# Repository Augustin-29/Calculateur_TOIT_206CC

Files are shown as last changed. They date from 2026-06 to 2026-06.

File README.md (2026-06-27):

# Calculateur TOIT 206CC (Version 1)

Ce projet open-source consiste en la rétro-ingénierie et la conception d'un calculateur de remplacement sur mesure pour la gestion du toit escamotable d'une Peugeot 206 CC. La V1 s'appuie sur une architecture matérielle moderne et un système d'exploitation temps réel pour piloter de manière fiable et sécurisée le cycle d'ouverture/fermeture du toit.

---

## 🛠️ Architecture du Projet

Le dépôt regroupe l'ensemble du projet dans une structure centralisée :
*   **`CAO/`** : Conception matérielle complète sous KiCad (Schématiques, empreintes spécifiques, modélisations 3D et fichiers de fabrication Gerber).
*   **`CODE_CT_V1/`** : Logiciel embarqué développé en C/C++ avec une structure de build basée sur CMake.

---

## 💾 Spécifications Techniques (Hardware)

Le module remplace l'électronique d'origine en modernisant la chaîne de traitement et de commande.

*   **Microcontrôleur principal** : STM32F103 (Cortex-M3), choisi pour sa gestion des périphériques et ses timers avancés nécessaires à l'acquisition des capteurs de position.
*   **Interface Véhicule & Diagnostic** : Support de la ligne K (K-line) pour la communication de diagnostic et l'analyse de protocole.
*   **Connectique d'Origine** : Intégration sur le PCB d'une empreinte sur mesure pour le connecteur jaune 26 broches spécifique au faisceau habitacle de la 206 CC.
*   **Routage & Puissance** : 
    *   Routage optimisé des pistes de puissance pour la gestion des courants des moteurs de pompe hydraulique et des actionneurs.
    *   Protection renforcée de l'étage d'alimentation face aux contraintes du réseau électrique automobile (transitoires, variations de tension).
    *   Isolation et conditionnement des signaux des micro-contacts (capteurs de fin de course des éléments du toit et du coffre).

---

## 💻 Logiciel Embarqué (Firmware)

Le code est architecturé pour garantir le déterminisme et la sécurité lors des mouvements mécaniques du toit.

*   **Système d'Exploitation** : Intégration de **FreeRTOS** pour orchestrer les tâches concurrentes (gestion de la machine d'état du toit, scrutation des capteurs, communications).
*   **Gestion de la Sécurité** : Tâches prioritaires surveillant en temps réel l'état des capteurs pour interrompre immédiatement le cycle en cas d'anomalie ou d'obstacle.
*   **Environnement de Développement** : Configuration complète sous **CMake**, facilitant la cross-compilation avec la chaîne d'outils `gcc-arm-none-eabi`.

---

## 📂 Contenu du dossier CAO

Le dossier de conception électronique inclut :
*   Le schéma structurel (`.kicad_sch`) et le routage du PCB (`.kicad_pcb`).
*   Les fichiers de fabrication indispensables (Générés dans `CAO/gerber/` : couches de cuivre, masques de soudure, sérigraphies et fichiers de perçage `.drl`).
*   Les modèles 3D des composants spécifiques (relais automobiles, connecteur jaune 26P, etc.) utilisés pour valider l'intégration mécanique de la carte dans son boîtier.

---

## 🚀 À venir (Roadmap V2)

*   Validation de la machine d'état sur banc de test et intégration véhicule.
*

---
*Projet développé par Augustin — 2026.*

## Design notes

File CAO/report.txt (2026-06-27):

Info: Traitement du symbole "C1:Capacitor_SMD:CP_Elec_8x10.5".
Info: Traitement du symbole "R12:Resistor_SMD:R_0805_2012Metric_Pad1.20x1.40mm_HandSolder".
Info: Traitement du symbole "C6:Capacitor_SMD:C_0805_2012Metric_Pad1.18x1.45mm_HandSolder".
Info: Traitement du symbole "R15:Resistor_SMD:R_0805_2012Metric_Pad1.20x1.40mm_HandSolder".
Info: Traitement du symbole "R7:Resistor_SMD:R_0805_2012Metric_Pad1.20x1.40mm_HandSolder".
Info: Traitement du symbole "J2:Connecteur_Jaune_206CC_26P:Connecteur_Jaune_206CC_15P".
Info: Traitement du symbole "D4:Diode_SMD:D_MiniMELF".
Info: Traitement du symbole "D7:Diode_SMD:D_SMA".
Info: Traitement du symbole "C11:Capacitor_SMD:C_0805_2012Metric_Pad1.18x1.45mm_HandSolder".
Info: Traitement du symbole "J3:Connector_PinSocket_2.54mm:PinSocket_1x07_P2.54mm_Vertical".
Info: Traitement du symbole "C15:Capacitor_SMD:C_1206_3216Metric".
Info: Traitement du symbole "D1:Diode_SMD:D_SMA".
Info: Traitement du symbole "R1:Resistor_SMD:R_0805_2012Metric_Pad1.20x1.40mm_HandSolder".
Info: Traitement du symbole "C2:Capacitor_SMD:C_0805_2012Metric_Pad1.18x1.45mm_HandSolder".
Info: Traitement du symbole "R23:Resistor_SMD:R_0805_2012Metric_Pad1.20x1.40mm_HandSolder".
Info: Traitement du symbole "R13:Resistor_SMD:R_0805_2012Metric_Pad1.20x1.40mm_HandSolder".
Info: Traitement du symbole "C7:Capacitor_SMD:C_0805_2012Metric_Pad1.18x1.45mm_HandSolder".
Info: Traitement du symbole "J1:Connecteur_Jaune_206CC_26P:Connecteur_Jaune_206CC_26P".
Info: Traitement du symbole "C19:Capacitor_SMD:C_0805_2012Metric_Pad1.18x1.45mm_HandSolder".
Info: Traitement du symbole "R21:Resistor_SMD:R_0805_2012Metric_Pad1.20x1.40mm_HandSolder".
Info: Traitement du symbole "R19:Resistor_SMD:R_0805_2012Metric_Pad1.20x1.40mm_HandSolder".
Info: Traitement du symbole "R3:Resistor_SMD:R_0805_2012Metric_Pad1.20x1.40mm_HandSolder".
Info: Traitement du symbole "R6:Resistor_SMD:R_0805_2012Metric_Pad1.20x1.40mm_HandSolder".
Info: Traitement du symbole "C12:Capacitor_SMD:C_0805_2012Metric_Pad1.18x1.45mm_HandSolder".
Info: Traitement du symbole "R17:Resistor_SMD:R_0805_2012Metric_Pad1.20x1.40mm_HandSolder".
Info: Traitement du symbole "C3:Capacitor_Tantalum_SMD:CP_EIA-3216-18_Kemet-A_HandSolder".
Info: Traitement du symbole "D5:Diode_THT:D_DO-41_SOD81_P10.16mm_Horizontal".
Info: Traitement du symbole "C16:Capacitor_SMD:C_1206_3216Metric".
Info: Traitement du symbole "R14:Resistor_SMD:R_0805_2012Metric_Pad1.20x1.40mm_HandSolder".
Info: Traitement du symbole "R16:Resistor_SMD:R_0805_2012Metric_Pad1.20x1.40mm_HandSolder".
Info: Traitement du symbole "C8:Capacitor_SMD:C_0805_2012Metric_Pad1.18x1.45mm_HandSolder".
Info: Traitement du symbole "D8:Diode_SMD:D_MiniMELF".
Info: Traitement du symbole "D2:Diode_SMD:D_SMA".
Info: Traitement du symbole "R22:Resistor_SMD:R_0805_2012Metric_Pad1.20x1.40mm_HandSolder".
Info: Traitement du symbole "K2:empreinte:EX2_NEC".
Info: Traitement du symbole "C20:Capacitor_SMD:C_0805_2012Metric_Pad1.18x1.45mm_HandSolder".
Info: Traitement du symbole "K1:empreinte:EX2_NEC".
Info: Traitement du symbole "K3:empreinte:EX2_NEC".
Info: Traitement du symbole "C4:Capacitor_SMD:C_0805_2012Metric_Pad1.18x1.45mm_HandSolder".
Info: Traitement du symbole "C13:Capacitor_SMD:C_0805_2012Metric_Pad1.18x1.45mm_HandSolder".
Info: Traitement du symbole "Q1:Package_TO_SOT_SMD:SOT-23".
Info: Traitement du symbole "R18:Resistor_SMD:R_0805_2012Metric_Pad1.20x1.40mm_HandSolder".
Info: Traitement du symbole "R5:Resistor_SMD:R_0805_2012Metric_Pad1.20x1.40mm_HandSolder".
Info: Traitement du symbole "C9:Capacitor_SMD:C_0805_2012Metric_Pad1.18x1.45mm_HandSolder".
Info: Traitement du symbole "R10:Resistor_SMD:R_0805_2012Metric_Pad1.20x1.40mm_HandSolder".
Info: Traitement du symbole "C17:Capacitor_SMD:C_1206_3216Metric".
Info: Traitement du symbole "R2:Resistor_SMD:R_0805_2012Metric_Pad1.20x1.40mm_HandSolder".
Info: Traitement du symbole "D6:Diode_SMD:D_SMA".
Info: Traitement du symbole "R11:Resistor_SMD:R_0805_2012Metric_Pad1.20x1.40mm_HandSolder".
Info: Traitement du symbole "D3:Diode_SMD:D_MiniMELF".
Info: Traitement du symbole "C5:Capacitor_SMD:C_0805_2012Metric_Pad1.18x1.45mm_HandSolder".
Info: Traitement du symbole "R40:Resistor_SMD:R_0805_2012Metric_Pad1.20x1.40mm_HandSolder".
Info: Traitement du symbole "R9:Resistor_SMD:R_0805_2012Metric_Pad1.20x1.40mm_HandSolder".
Info: Traitement du symbole "C21:Capacitor_SMD:C_0805_2012Metric_Pad1.18x1.45mm_HandSolder".
Info: Traitement du symbole "C14:Capacitor_SMD:C_1206_3216Metric".
Info: Traitement du symbole "D9:Diode_SMD:D_MiniMELF".
Info: Traitement du symbole "C10:Capacitor_SMD:C_0805_2012Metric_Pad1.18x1.45mm_HandSolder".
Info: Traitement du symbole "J4:Connector_PinSocket_2.54mm:PinSocket_1x05_P2.54mm_Vertical".
Info: Traitement du symbole "R20:Resistor_SMD:R_0805_2012Metric_Pad1.20x1.40mm_HandSolder".
Info: Traitement du symbole "R8:Resistor_SMD:R_0805_2012Metric_Pad1.20x1.40mm_HandSolder".
Info: Traitement du symbole "R4:Resistor_SMD:R_0805_2012Metric_Pad1.20x1.40mm_HandSolder".
Info: Traitement du symbole "C18:Capacitor_SMD:C_0805_2012Metric_Pad1.18x1.45mm_HandSolder".
Info: Traitement du symbole "R24:Resistor_SMD:R_0805_2012Metric_Pad1.20x1.40mm_HandSolder".
Info: Traitement du symbole "R25:Resistor_SMD:R_0805_2012Metric_Pad1.20x1.40mm_HandSolder".
Info: Traitement du symbole "R26:Resistor_SMD:R_1206_3216Metric".
Info: Traitement du symbole "R27:Resistor_SMD:R_1206_3216Metric".
Info: Traitement du symbole "R28:Resistor_SMD:R_0805_2012Metric_Pad1.20x1.40mm_HandSolder".
Info: Traitement du symbole "R29:Resistor_SMD:R_0805_2012Metric_Pad1.20x1.40mm_HandSolder".
Info: Traitement du symbole "R30:Resistor_SMD:R_0805_2012Metric_Pad1.20x1.40mm_HandSolder".
Info: Traitement du symbole "R31:Resistor_SMD:R_0805_2012Metric_Pad1.20x1.40mm_HandSolder".
Info: Traitement du symbole "R32:Resistor_SMD:R_0805_2012Metric_Pad1.20x1.40mm_HandSolder".
Info: Traitement du symbole "R33:Resistor_SMD:R_0805_2012Metric_Pad1.20x1.40mm_HandSolder".
Info: Traitement du symbole "R34:Resistor_SMD:R_0805_2012Metric_Pad1.20x1.40mm_HandSolder".
Info: Traitement du symbole "R35:Resistor_SMD:R_0805_2012Metric_Pad1.20x1.40mm_HandSolder".
Info: Traitement du symbole "R36:Resistor_SMD:R_1206_3216Metric".
Info: Traitement du symbole "R37:Resistor_SMD:R_1206_3216Metric".
Info: Traitement du symbole "R38:Resistor_SMD:R_0805_2012Metric_Pad1.20x1.40mm_HandSolder".
Info: Traitement du symbole "R39:Resistor_SMD:R_0805_2012Metric_Pad1.20x1.40mm_HandSolder".
Info: Traitement du symbole "R41:Resistor_SMD:R_0805_2012Metric_Pad1.20x1.40mm_HandSolder".
Info: Traitement du symbole "R42:Resistor_SMD:R_0805_2012Metric_Pad1.20x1.40mm_HandSolder".
Info: Traitement du symbole "R43:Resistor_SMD:R_0805_2012Metric_Pad1.20x1.40mm_HandSolder".
Info: Traitement du symbole "R44:Resistor_SMD:R_0805_2012Metric_Pad1.20x1.40mm_HandSolder".
Info: Traitement du symbole "R45:Resistor_SMD:R_0805_2012Metric_Pad1.20x1.40mm_HandSolder".
Info: Traitement du symbole "R46:Resistor_SMD:R_0805_2012Metric_Pad1.20x1.40mm_HandSolder".
Info: Traitement du symbole "R47:Resistor_SMD:R_0805_2012Metric_Pad1.20x1.40mm_HandSolder".
Info: Traitement du symbole "R48:Resistor_SMD:R_0805_2012Metric_Pad1.20x1.40mm_HandSolder".
Info: Traitement du symbole "R49:Resistor_SMD:R_0805_2012Metric_Pad1.20x1.40mm_HandSolder".
Info: Traitement du symbole "R50:Resistor_SMD:R_0805_2012Metric_Pad1.20x1.40mm_HandSolder".
Info: Traitement du symbole "R51:Resistor_SMD:R_0805_2012Metric_Pad1.20x1.40mm_HandSolder".
Info: Traitement du symbole "R52:Resistor_SMD:R_0805_2012Metric_Pad1.20x1.40mm_HandSolder".
Info: Traitement du symbole "R53:Resistor_SMD:R_0805_2012Metric_Pad1.20x1.40mm_HandSolder".
Info: Traitement du symbole "R54:Resistor_SMD:R_0805_2012Metric_Pad1.20x1.40mm_HandSolder".
Info: Traitement du symbole "R55:Resistor_SMD:R_0805_2012Metric_Pad1.20x1.40mm_HandSolder".
Info: Traitement du symbole "R56:Resistor_SMD:R_1206_3216Metric".
Info: Traitement du symbole "R57:Resistor_SMD:R_1206_3216Metric".
Info: Traitement du symbole "R_Shunt_1:Resistor_SMD:R_Shunt_Vishay_WSR2_WSR3".
Info: Traitement du symbole "R_Shunt_2:Resistor_SMD:R_Shunt_Vishay_WSR2_WSR3".
Info: Traitement du symbole "R_Shunt_3:Resistor_SMD:R_Shunt_Vishay_WSR2_WSR3".
Info: Traitement du symbole "R_Shunt_4:Resistor_SMD:R_Shunt_Vishay_WSR2_WSR3".
Info: Traitement du symbole "U1:Converter_DCDC:Converter_DCDC_TRACO_TSR-1_THT".
Info: Traitement du symbole "U2:Package_QFP:LQFP-64_10x10mm_P0.5mm".
Info: Traitement du symbole "U3:Package_SO:SOIC-16_4.55x10.3mm_P1.27mm".
Info: Traitement du symbole "U4:Package_SO:SOIC-16_4.55x10.3mm_P1.27mm".
Info: Traitement du symbole "U5:Package_SO:SOIC-16_4.55x10.3mm_P1.27mm".
Info: Traitement du symbole "U6:Package_SO:SOIC-16_4.55x10.3mm_P1.27mm".
Info: Traitement du symbole "U7:Package_SO:Infineon_SOIC-20W_7.6x12.8mm_P1.27mm".
Info: Traitement du symbole "U9:Package_SO:SOIC-8_3.9x4.9mm_P1.27mm".
Info: Traitement du symbole "U10:RF_Module:Microchip_RN4871".
Info: Traitement du symbole "U11:Package_DIP:DIP-18_W7.62mm".
Info: Traitement du symbole "Y1:Crystal:Crystal_SMD_5032-4Pin_5.0x3.2mm".
Modifie valeur C5 de C_0805_2012Metric_Pad1.18x1.45mm_HandSolder en 100nf.
Mise à jour C5 association de symbole de  à /be16f0ff-4f4a-47e4-9a36-cbf28c4784df.
Mise a Jour des Champs de C5.
Mis à jour C5 nom de feuille en /.
Mis à jour C5 fichier de feuille en caculateur.kicad_sch.
Filtres d'empreinte C5 mis à jour en 'C_*'.
Ajout net Net-(D3-K).
Connecter C5 pin 1 à Net-(D3-K).
Connecter C5 pin 2 à GND.
Métadonnées de l'unité C5 mises à jour.
Ajouté C6 (empreinte 'Capacitor_SMD:C_0805_2012Metric_Pad1.18x1.45mm_HandSolder').
Change la référence schématique de REF** en C6.
Modifie valeur C6 de C_0805_2012Metric_Pad1.18x1.45mm_HandSolder en 100nf.
Mise à jour C6 association de symbole de  à /65ad52e4-93e2-41a9-8602-873f64c461d2.
Mise a Jour des Champs de C6.
Mis à jour C6 nom de feuille en /.
Mis à jour C6 fichier de feuille en caculateur.kicad_sch.
Filtres d'empreinte C6 mis à jour en 'C_*'.
Connecter C6 pin 2 à GND.
Ajout net Net-(U2-NRST).
Connecter C6 pin 1 à Net-(U2-NRST).
Métadonnées de l'unité C6 mises à jour.
Ajouté C7 (empreinte 'Capacitor_SMD:C_0805_2012Metric_Pad1.18x1.45mm_HandSolder').
Change la référence schématique de REF** en C7.
Modifie valeur C7 de C_0805_2012Metric_Pad1.18x1.45mm_HandSolder en 100nf.
Mise à jour C7 association de symbole de  à /0b7f2c41-c607-44ba-82bd-c58df4c708f6.
Mise a Jour des Champs de C7.
Mis à jour C7 nom de feuille en /.
Mis à jour C7 fichier de feuille en caculateur.kicad_sch.
Filtres d'empreinte C7 mis à jour en 'C_*'.
Connecter C7 pin 2 à GND.
Ajout net Net-(U2-VBAT).
Connecter C7 pin 1 à Net-(U2-VBAT).
Métadonnées de l'unité C7 mises à jour.
Ajouté C8 (empreinte 'Capacitor_SMD:C_0805_2012Metric_Pad1.18x1.45mm_HandSolder').
Change la référence schématique de REF** en C8.
Modifie valeur C8 de C_0805_2012Metric_Pad1.18x1.45mm_HandSolder en 100nf.
Mise à jour C8 association de symbole de  à /8b1f4b69-5571-46f1-8e4b-f9b47eb149fe.
Mise a Jour des Champs de C8.
Mis à jour C8 nom de feuille en /.
Mis à jour C8 fichier de feuille en caculateur.kicad_sch.
Filtres d'empreinte C8 mis à jour en 'C_*'.
Connecter C8 pin 2 à GND.
Connecter C8 pin 1 à Net-(U2-VBAT).
Métadonnées de l'unité C8 mises à jour.
Ajouté C9 (empreinte 'Capacitor_SMD:C_0805_2012Metric_Pad1.18x1.45mm_HandSolder').
Change la référence schématique de REF** en C9.
Modifie valeur C9 de C_0805_2012Metric_Pad1.18x1.45mm_HandSolder en 100nf.
Mise à jour C9 association de symbole de  à /7cc02d3f-8e73-4aa3-98d1-2f72e6aa8ebc.
Mise a Jour des Champs de C9.
Mis à jour C9 nom de feuille en /.
Mis à jour C9 fichier de feuille en caculateur.kicad_sch.
Filtres d'empreinte C9 mis à jour en 'C_*'.
Connecter C9 pin 1 à Net-(U2-VBAT).
Connecter C9 pin 2 à GND.
Métadonnées de l'unité C9 mises à jour.
Ajouté C10 (empreinte 'Capacitor_SMD:C_0805_2012Metric_Pad1.18x1.45mm_HandSolder').
Change la référence schématique de REF** en C10.
Modifie valeur C10 de C_0805_2012Metric_Pad1.18x1.45mm_HandSolder en 100nf.
Mise à jour C10 association de symbole de  à /bca4cdbf-02e1-4ff5-8a3f-3d5c49f89ddf.
Mise a Jour des Champs de C10.
Mis à jour C10 nom de feuille en /.
Mis à jour C10 fichier de feuille en caculateur.kicad_sch.
Filtres d'empreinte C10 mis à jour en 'C_*'.
Connecter C10 pin 2 à GND.
Connecter C10 pin 1 à Net-(U2-VBAT).
Métadonnées de l'unité C10 mises à jour.
Ajouté C11 (empreinte 'Capacitor_SMD:C_0805_2012Metric_Pad1.18x1.45mm_HandSolder').
Change la référence schématique de REF** en C11.
Modifie valeur C11 de C_0805_2012Metric_Pad1.18x1.45mm_HandSolder en 100nf.
Mise à jour C11 association de symbole de  à /995ef40d-64e5-4725-a92f-a18b8c27cd9a.
Mise a Jour des Champs de C11.
Mis à jour C11 nom de feuille en /.
Mis à jour C11 fichier de feuille en caculateur.kicad_sch.
Filtres d'empreinte C11 mis à jour en 'C_*'.
Ajout net Net-(D4-K).
Connecter C11 pin 1 à Net-(D4-K).
Connecter C11 pin 2 à GND.
Métadonnées de l'unité C11 mises à jour.
Ajouté C12 (empreinte 'Capacitor_SMD:C_0805_2012Metric_Pad1.18x1.45mm_HandSolder').
Change la référence schématique de REF** en C12.
Modifie valeur C12 de C_0805_2012Metric_Pad1.18x1.45mm_HandSolder en 100nf.
Mise à jour C12 association de symbole de  à /c298c9d3-817d-42c9-bf9b-cd972ccb9abb.
Mise a Jour des Champs de C12.
Mis à jour C12 nom de feuille en /.
Mis à jour C12 fichier de feuille en caculateur.kicad_sch.
Filtres d'empreinte C12 mis à jour en 'C_*'.
Connecter C12 pin 2 à GND.
Ajout net VBB.
Connecter C12 pin 1 à VBB.
Métadonnées de l'unité C12 mises à jour.
Ajouté C13 (empreinte 'Capacitor_SMD:C_0805_2012Metric_Pad1.18x1.45mm_HandSolder').
Change la référence schématique de REF** en C13.
Modifie valeur C13 de C_0805_2012Metric_Pad1.18x1.45mm_HandSolder en 100nf.
Mise à jour C13 association de symbole de  à /245f3d8b-49ff-444f-b512-ac56e169d5bc.
Mise a Jour des Champs de C13.
Mis à jour C13 nom de feuille en /.
Mis à jour C13 fichier de feuille en caculateur.kicad_sch.
Filtres d'empreinte C13 mis à jour en 'C_*'.
Ajout net Net-(U9A-+).
Connecter C13 pin 2 à Net-(U9A-+).
Connecter C13 pin 1 à GND.
Métadonnées de l'unité C13 mises à jour.
Ajouté C14 (empreinte 'Capacitor_SMD:C_1206_3216Metric').
Change la référence schématique de REF** en C14.
Modifie valeur C14 de C_1206_3216Metric en 12nF.
Mise à jour C14 association de symbole de  à /5a1450ea-3a96-4cab-8d40-f784ad8079a7.
Mise a Jour des Champs de C14.
Mis à jour C14 nom de feuille en /.
Mis à jour C14 fichier de feuille en caculateur.kicad_sch.
Filtres d'empreinte C14 mis à jour en 'C_*'.
Ajout net Net-(J2-Pin_6).
Connecter C14 pin 2 à Net-(J2-Pin_6).
Ajout net Net-(J2-Pin_14).
Connecter C14 pin 1 à Net-(J2-Pin_14).
Métadonnées de l'unité C14 mises à jour.
Ajouté C15 (empreinte 'Capacitor_SMD:C_1206_3216Metric').
Change la référence schématique de REF** en C15.
Modifie valeur C15 de C_1206_3216Metric en 12nF.
Mise à jour C15 association de symbole de  à /f561a217-28f9-4487-aeff-c327a70189af.
Mise a Jour des Champs de C15.
Mis à jour C15 nom de feuille en /.
Mis à jour C15 fichier de feuille en caculateur.kicad_sch.
Filtres d'empreinte C15 mis à jour en 'C_*'.
Ajout net Net-(J2-Pin_7).
Connecter C15 pin 2 à Net-(J2-Pin_7).
Connecter C15 pin 1 à Net-(J2-Pin_14).
Métadonnées de l'unité C15 mises à jour.
Ajouté C16 (empreinte 'Capacitor_SMD:C_1206_3216Metric').
Change la référence schématique de REF** en C16.
Modifie valeur C16 de C_1206_3216Metric en 12nF.
Mise à jour C16 association de symbole de  à /fe2f91c4-55fe-439d-a678-3d6d8ea82e9d.
Mise a Jour des Champs de C16.
Mis à jour C16 nom de feuille en /.
Mis à jour C16 fichier de feuille en caculateur.kicad_sch.
Filtres d'empreinte C16 mis à jour en 'C_*'.
Ajout net Net-(J2-Pin_5).
Connecter C16 pin 2 à Net-(J2-Pin_5).
Ajout net Net-(J2-Pin_13).
Connecter C16 pin 1 à Net-(J2-Pin_13).
Métadonnées de l'unité C16 mises à jour.
Ajouté C17 (empreinte 'Capacitor_SMD:C_1206_3216Metric').
Change la référence schématique de REF** en C17.
Modifie valeur C17 de C_1206_3216Metric en 12nF.
Mise à jour C17 association de symbole de  à /3d29e288-ca9d-428a-9eb5-39306c232604.
Mise a Jour des Champs de C17.
Mis à jour C17 nom de feuille en /.
Mis à jour C17 fichier de feuille en caculateur.kicad_sch.
Filtres d'empreinte C17 mis à jour en 'C_*'.
Ajout net Net-(J2-Pin_12).
Connecter C17 pin 1 à Net-(J2-Pin_12).
Connecter C17 pin 2 à Net-(J2-Pin_5).
Métadonnées de l'unité C17 mises à jour.
Ajouté C18 (empreinte 'Capacitor_SMD:C_0805_2012Metric_Pad1.18x1.45mm_HandSolder').
Change la référence schématique de REF** en C18.
Modifie valeur C18 de C_0805_2012Metric_Pad1.18x1.45mm_HandSolder en 100nf.
Mise à jour C18 association de symbole de  à /333eec3f-0aaa-4c50-b7b2-62ec7b72bd66.
Mise a Jour des Champs de C18.
Mis à jour C18 nom de feuille en /.
Mis à jour C18 fichier de feuille en caculateur.kicad_sch.
Filtres d'empreinte C18 mis à jour en 'C_*'.
Ajout net Net-(U9B-+).
Connecter C18 pin 2 à Net-(U9B-+).
Connecter C18 pin 1 à GND.
Métadonnées de l'unité C18 mises à jour.
Ajouté C19 (empreinte 'Capacitor_SMD:C_0805_2012Metric_Pad1.18x1.45mm_HandSolder').
Change la référence schématique de REF** en C19.
Modifie valeur C19 de C_0805_2012Metric_Pad1.18x1.45mm_HandSolder en 12pF.
Mise à jour C19 association de symbole de  à /1f1e0ca7-567d-4f72-9315-879b6e50b48d.
Mise a Jour des Champs de C19.
Mis à jour C19 nom de feuille en /.
Mis à jour C19 fichier de feuille en caculateur.kicad_sch.
Filtres d'empreinte C19 mis à jour en 'C_*'.
Connecter C19 pin 1 à GND.
Ajout net Net-(U2-PD0).
Connecter C19 pin 2 à Net-(U2-PD0).
Métadonnées de l'unité C19 mises à jour.
Ajouté C20 (empreinte 'Capacitor_SMD:C_0805_2012Metric_Pad1.18x1.45mm_HandSolder').
Change la référence schématique de REF** en C20.
Modifie valeur C20 de C_0805_2012Metric_Pad1.18x1.45mm_HandSolder en 12pF.
Mise à jour C20 association de symbole de  à /a1ce096c-9381-464c-93fd-bad1373e2a09.
Mise a Jour des Champs de C20.
Mis à jour C20 nom de feuille en /.
Mis à jour C20 fichier de feuille en caculateur.kicad_sch.
Filtres d'empreinte C20 mis à jour en 'C_*'.
Connecter C20 pin 2 à GND.
Ajout net Net-(U2-PD1).
Connecter C20 pin 1 à Net-(U2-PD1).
Métadonnées de l'unité C20 mises à jour.
Ajouté C21 (empreinte 'Capacitor_SMD:C_0805_2012Metric_Pad1.18x1.45mm_HandSolder').
Change la référence schématique de REF** en C21.
Modifie valeur C21 de C_0805_2012Metric_Pad1.18x1.45mm_HandSolder en 100nf.
Mise à jour C21 association de symbole de  à /68b67e83-218e-4472-8722-eed8791aa8a4.
Mise a Jour des Champs de C21.
Mis à jour C21 nom de feuille en /.
Mis à jour C21 fichier de feuille en caculateur.kicad_sch.
Filtres d'empreinte C21 mis à jour en 'C_*'.
Ajout net Net-(U10-VBAT).
Connecter C21 pin 1 à Net-(U10-VBAT).
Connecter C21 pin 2 à GND.
Métadonnées de l'unité C21 mises à jour.
Ajouté D1 (empreinte 'Diode_SMD:D_SMA').
Change la référence schématique de REF** en D1.
Modifie valeur D1 de D_SMA en SS34.
Mise à jour D1 association de symbole de  à /a52fb3a2-46ab-4557-9cad-e2539e2375e8.
Mise a Jour des Champs de D1.
Mis à jour D1 nom de feuille en /.
Mis à jour D1 fichier de feuille en caculateur.kicad_sch.
Filtres d'empreinte D1 mis à jour en 'D*SMA*'.
Ajout net Net-(D1-K).
Connecter D1 pin 1 à Net-(D1-K).
Ajout net Net-(D1-A).
Connecter D1 pin 2 à Net-(D1-A).
Métadonnées de l'unité D1 mises à jour.
Ajouté D2 (empreinte 'Diode_SMD:D_SMA').
Change la référence schématique de REF** en D2.
Modifie valeur D2 de D_SMA en SMAJ24A.
Mise à jour D2 association de symbole de  à /12cd1e6c-7444-427f-8c5a-407a91d99e3a.
Mise a Jour des Champs de D2.
Mis à jour D2 nom de feuille en /.
Mis à jour D2 fichier de feuille en caculateur.kicad_sch.
Filtres d'empreinte D2 mis à jour en 'D*SMA*'.
Connecter D2 pin 2 à GND.
Connecter D2 pin 1 à Net-(D1-K).
Métadonnées de l'unité D2 mises à jour.
Ajouté D3 (empreinte 'Diode_SMD:D_MiniMELF').
Change la référence schématique de REF** en D3.
Modifie valeur D3 de D_MiniMELF en BZV55B3V3.
Mise à jour D3 association de symbole de  à /985dd229-46e4-4988-b0b4-0a1a3eb4a86d.
Mise a Jour des Champs de D3.
Mis à jour D3 nom de feuille en /.
Mis à jour D3 fichier de feuille en caculateur.kicad_sch.
Filtres d'empreinte D3 mis à jour en 'D*MiniMELF*'.
Connecter D3 pin 2 à GND.
Connecter D3 pin 1 à Net-(D3-K).
Métadonnées de l'unité D3 mises à jour.
Ajouté D4 (empreinte 'Diode_SMD:D_MiniMELF').
Change la référence schématique de REF** en D4.
Modifie valeur D4 de D_MiniMELF en BZV55B3V3.
Mise à jour D4 association de symbole de  à /3f3faeb3-d059-4e14-be14-8dab7118ddc8.
Mise a Jour des Champs de D4.
Mis à jour D4 nom de feuille en /.
Mis à jour D4 fichier de feuille en caculateur.kicad_sch.
Filtres d'empreinte D4 mis à jour en 'D*MiniMELF*'.
Connecter D4 pin 2 à GND.
Connecter D4 pin 1 à Net-(D4-K).
Métadonnées de l'unité D4 mises à jour.
Ajouté D5 (empreinte 'Diode_THT:D_DO-41_SOD81_P10.16mm_Horizontal').
Change la référence schématique de REF** en D5.
Modifie valeur D5 de D_DO-41_SOD81_P10.16mm_Horizontal en 1N4007.
Mise à jour D5 association de symbole de  à /fabe3022-5fc9-47d7-9666-98f143ec3843.
Mise a Jour des Champs de D5.
Mis à jour D5 nom de feuille en /.
Mis à jour D5 fichier de feuille en caculateur.kicad_sch.
Filtres d'empreinte D5 mis à jour en 'D*DO?41*'.
Connecter D5 pin 1 à VBB.
Ajout net Net-(D5-A).
Connecter D5 pin 2 à Net-(D5-A).
Métadonnées de l'unité D5 mises à jour.
Ajouté D6 (empreinte 'Diode_SMD:D_SMA').
Change la référence schématique de REF** en D6.
Modifie valeur D6 de D_SMA en SS34.
Mise à jour D6 association de symbole de  à /bb1f069d-4c4c-41a6-8f5b-5243d58773e0.
Mise a Jour des Champs de D6.
Mis à jour D6 nom de feuille en /.
Mis à jour D6 fichier de feuille en caculateur.kicad_sch.
Filtres d'empreinte D6 mis à jour en 'D*SMA*'.
Ajout net Net-(D6-A).
Connecter D6 pin 2 à Net-(D6-A).
Connecter D6 pin 1 à GND.
Métadonnées de l'unité D6 mises à jour.
Ajouté D7 (empreinte 'Diode_SMD:D_SMA').
Change la référence schématique de REF** en D7.
Modifie valeur D7 de D_SMA en SS34.
Mise à jour D7 association de symbole de  à /231400cb-ce06-401c-8b20-e48fc415fd5b.
Mise a Jour des Champs de D7.
Mis à jour D7 nom de feuille en /.
Mis à jour D7 fichier de feuille en caculateur.kicad_sch.
Filtres d'empreinte D7 mis à jour en 'D*SMA*'.
Connecter D7 pin 1 à GND.
Ajout net Net-(D7-A).
Connecter D7 pin 2 à Net-(D7-A).
Métadonnées de l'unité D7 mises à jour.
Ajouté D8 (empreinte 'Diode_SMD:D_MiniMELF').
Change la référence schématique de REF** en D8.
Modifie valeur D8 de D_MiniMELF en BZV55B3V3.
Mise à jour D8 association de symbole de  à /4b87b08d-c0b9-4913-aac8-a05cbba66939.
Mise a Jour des Champs de D8.
Mis à jour D8 nom de feuille en /.
Mis à jour D8 fichier de feuille en caculateur.kicad_sch.
Filtres d'empreinte D8 mis à jour en 'D*MiniMELF*'.
Connecter D8 pin 2 à GND.
Ajout net Net-(D8-K).
Connecter D8 pin 1 à Net-(D8-K).
Métadonnées de l'unité D8 mises à jour.
Ajouté D9 (empreinte 'Diode_SMD:D_MiniMELF').
Change la référence schématique de REF** en D9.
Modifie valeur D9 de D_MiniMELF en BZV55B3V3.
Mise à jour D9 association de symbole de  à /bb81fd01-3625-494b-b90b-44d13c62422c.
Mise a Jour des Champs de D9.
Mis à jour D9 nom de feuille en /.
Mis à jour D9 fichier de feuille en caculateur.kicad_sch.
Filtres d'empreinte D9 mis à jour en 'D*MiniMELF*'.
Ajout net Net-(D9-K).
Connecter D9 pin 1 à Net-(D9-K).
Connecter D9 pin 2 à GND.
Métadonnées de l'unité D9 mises à jour.
Ajouté J1 (empreinte 'Connecteur_Jaune_206CC_26P:Connecteur_Jaune_206CC_26P').
Change la référence schématique de REF** en J1.
Modifie valeur J1 de Connecteur_Jaune_206CC_26P en Conn_02x13_commande.
Mise à jour J1 association de symbole de  à /097af051-9c7b-4353-8f4c-f058ae921a74.
Mise a Jour des Champs de J1.
Mis à jour J1 nom de feuille en /.
Mis à jour J1 fichier de feuille en caculateur.kicad_sch.
Filtres d'empreinte J1 mis à jour en 'Connector*:*_2x??_*'.
Ajout net Net-(J1-Pin_3).
Connecter J1 pin 3 à Net-(J1-Pin_3).
Ajout net Net-(J1-Pin_11).
Connecter J1 pin 11 à Net-(J1-Pin_11).
Connecter J1 pin 1 à Net-(D1-A).
Connecter J1 pin 19 à GND.
Connecter J1 pin 22 à GND.
Ajout net Net-(J1-Pin_18).
Connecter J1 pin 18 à Net-(J1-Pin_18).
Ajout net Net-(J1-Pin_25).
Connecter J1 pin 25 à Net-(J1-Pin_25).
Ajout net Net-(J1-Pin_10).
Connecter J1 pin 10 à Net-(J1-Pin_10).
Ajout net Net-(J1-Pin_16).
Connecter J1 pin 16 à Net-(J1-Pin_16).
Ajout net Net-(J1-Pin_4).
Connecter J1 pin 4 à Net-(J1-Pin_4).
Ajout net Net-(J1-Pin_2).
Connecter J1 pin 2 à Net-(J1-Pin_2).
Ajout net Net-(J1-Pin_8).
Connecter J1 pin 8 à Net-(J1-Pin_8).
Ajout net Net-(J1-Pin_5).
Connecter J1 pin 5 à Net-(J1-Pin_5).
Ajout net Net-(J1-Pin_7).
Connecter J1 pin 7 à Net-(J1-Pin_7).
Ajout net Net-(J1-Pin_21).
Connecter J1 pin 21 à Net-(J1-Pin_21).
Ajout net Net-(J1-Pin_13).
Connecter J1 pin 13 à Net-(J1-Pin_13).
Ajout net unconnected-(J1-Pin_14-Pad14).
Connecter J1 pin 14 à unconnected-(J1-Pin_14-Pad14).
Ajout net Net-(J1-Pin_9).
Connecter J1 pin 9 à Net-(J1-Pin_9).
Connecter J1 pin 26 à GND.
Ajout net Net-(J1-Pin_12).
Connecter J1 pin 12 à Net-(J1-Pin_12).
Ajout net Net-(J1-Pin_6).
Connecter J1 pin 6 à Net-(J1-Pin_6).
Ajout net Net-(J1-Pin_20).
Connecter J1 pin 20 à Net-(J1-Pin_20).
Ajout net Net-(J1-Pin_24).
Connecter J1 pin 24 à Net-(J1-Pin_24).
Ajout net Net-(J1-Pin_17).
Connecter J1 pin 17 à Net-(J1-Pin_17).
Ajout net Net-(J1-Pin_23).
Connecter J1 pin 23 à Net-(J1-Pin_23).
Ajout net Net-(J1-Pin_15).
Connecter J1 pin 15 à Net-(J1-Pin_15).
Métadonnées de l'unité J1 mises à jour.
Ajouté J2 (empreinte 'Connecteur_Jaune_206CC_26P:Connecteur_Jaune_206CC_15P').
Change la référence schématique de REF** en J2.
Modifie valeur J2 de Connecteur_Jaune_206CC_15P en Conn_02x08_alimentation.
Mise à jour J2 association de symbole de  à /46f3ffba-5c25-474c-a6c3-f0842bf122fb.
Mise a Jour des Champs de J2.
Mis à jour J2 nom de feuille en /.
Mis à jour J2 fichier de feuille en caculateur.kicad_sch.
Filtres d'empreinte J2 mis à jour en 'Connector*:*_2x??_*'.
Ajout net GNDPWR.
Connecter J2 pin 15 à GNDPWR.
Connecter J2 pin 11 à VBB.
Connecter J2 pin 7 à Net-(J2-Pin_7).
Connecter J2 pin 12 à Net-(J2-Pin_12).
Connecter J2 pin 13 à Net-(J2-Pin_13).
Connecter J2 pin 14 à Net-(J2-Pin_14).
Ajout net Net-(J2-Pin_10).
Connecter J2 pin 10 à Net-(J2-Pin_10).
Connecter J2 pin 8 à GNDPWR.
Connecter J2 pin 4 à VBB.
Connecter J2 pin 5 à Net-(J2-Pin_5).
Connecter J2 pin 6 à Net-(J2-Pin_6).
Ajout net unconnected-(J2-Pin_3-Pad3).
Connecter J2 pin 3 à unconnected-(J2-Pin_3-Pad3).
Ajout net Net-(J2-Pin_2).
Connecter J2 pin 2 à Net-(J2-Pin_2).
Ajout net Net-(J2-Pin_9).
Connecter J2 pin 9 à Net-(J2-Pin_9).
Ajout net Net-(J2-Pin_1).
Connecter J2 pin 1 à Net-(J2-Pin_1).
Métadonnées de l'unité J2 mises à jour.
Ajouté J3 (empreinte 'Connector_PinSocket_2.54mm:PinSocket_1x07_P2.54mm_Vertical').
Change la référence schématique de REF** en J3.
Modifie valeur J3 de PinSocket_1x07_P2.54mm_Vertical en Conn_01x07_Additionnel.
Mise à jour J3 association de symbole de  à /a39c0dd5-a1a4-419b-9e02-3f781e1c37d9.
Mise a Jour des Champs de J3.
Mis à jour J3 nom de feuille en /.
Mis à jour J3 fichier de feuille en caculateur.kicad_sch.
Filtres d'empreinte J3 mis à jour en 'Connector*:*_1x??_*'.
Ajout net Net-(J3-Pin_1).
Connecter J3 pin 1 à Net-(J3-Pin_1).
Ajout net Net-(J3-Pin_3).
Connecter J3 pin 3 à Net-(J3-Pin_3).
Ajout net Net-(J3-Pin_7).
Connecter J3 pin 7 à Net-(J3-Pin_7).
Ajout net Net-(J3-Pin_6).
Connecter J3 pin 6 à Net-(J3-Pin_6).
Ajout net Net-(J3-Pin_5).
Connecter J3 pin 5 à Net-(J3-Pin_5).
Ajout net Net-(J3-Pin_2).
Connecter J3 pin 2 à Net-(J3-Pin_2).
Connecter J3 pin 4 à GND.
Métadonnées de l'unité J3 mises à jour.
Ajouté J4 (empreinte 'Connector_PinSocket_2.54mm:PinSocket_1x05_P2.54mm_Vertical').
Change la référence schématique de REF** en J4.
Modifie valeur J4 de PinSocket_1x05_P2.54mm_Vertical en Conn_01x05_SWD.
Mise à jour J4 association de symbole de  à /871e2402-2648-433d-975c-1f0cca420c0d.
Mise a Jour des Champs de J4.
Mis à jour J4 nom de feuille en /.
Mis à jour J4 fichier de feuille en caculateur.kicad_sch.
Filtres d'empreinte J4 mis à jour en 'Connector*:*_1x??_*'.
Ajout net Net-(J4-Pin_5).
Connecter J4 pin 5 à Net-(J4-Pin_5).
Connecter J4 pin 3 à GND.
Ajout net Net-(J4-Pin_4).
Connecter J4 pin 4 à Net-(J4-Pin_4).
Ajout net Net-(J4-Pin_2).
Connecter J4 pin 2 à Net-(J4-Pin_2).
Ajout net Net-(J4-Pin_1).
Connecter J4 pin 1 à Net-(J4-Pin_1).
Métadonnées de l'unité J4 mises à jour.
Ajouté K1 (empreinte 'empreinte:EX2_NEC').
Change la référence schématique de REF** en K1.
Modifie valeur K1 de EX2_NEC en EX2-2U1S.
Mise à jour K1 association de symbole de  à /771189ee-7179-4efb-b504-b1dd5ae00074.
Mise a Jour des Champs de K1.
Mis à jour K1 nom de feuille en /.
Mis à jour K1 fichier de feuille en caculateur.kicad_sch.
Filtres d'empreinte K1 mis à jour en 'EX2_NEC'.
Ajout net Net-(K1-Pad2).
Connecter K1 pin 2 à Net-(K1-Pad2).
Ajout net Net-(K1-Pad6).
Connecter K1 pin 6 à Net-(K1-Pad6).
Ajout net Net-(K1-Pad1).
Connecter K1 pin 1 à Net-(K1-Pad1).
Ajout net Net-(K1-Pad10).
Connecter K1 pin 10 à Net-(K1-Pad10).
Ajout net Net-(K1-Pad3).
Connecter K1 pin 3 à Net-(K1-Pad3).
Connecter K1 pin 5 à VBB.
Ajout net Net-(K1-Pad7).
Connecter K1 pin 7 à Net-(K1-Pad7).
Ajout net Net-(K1-Pad8).
Connecter K1 pin 8 à Net-(K1-Pad8).
Connecter K1 pin 4 à Net-(K1-Pad10).
Connecter K1 pin 9 à VBB.
Métadonnées de l'unité K1 mises à jour.
Ajouté K2 (empreinte 'empreinte:EX2_NEC').
Change la référence schématique de REF** en K2.
Modifie valeur K2 de EX2_NEC en EX2-2U1S.
Mise à jour K2 association de symbole de  à /f7f7be18-5580-43ee-868f-3acad033d22b.
Mise a Jour des Champs de K2.
Mis à jour K2 nom de feuille en /.
Mis à jour K2 fichier de feuille en caculateur.kicad_sch.
Filtres d'empreinte K2 mis à jour en 'EX2_NEC'.
Connecter K2 pin 4 à Net-(K1-Pad10).
Ajout net Net-(K2-Pad3).
Connecter K2 pin 3 à Net-(K2-Pad3).
Ajout net Net-(K2-Pad1).
Connecter K2 pin 1 à Net-(K2-Pad1).
Ajout net Net-(K2-Pad8).
Connecter K2 pin 8 à Net-(K2-Pad8).
Ajout net Net-(K2-Pad7).
Connecter K2 pin 7 à Net-(K2-Pad7).
Ajout net Net-(K2-Pad2).
Connecter K2 pin 2 à Net-(K2-Pad2).
Ajout net Net-(K2-Pad10).
Connecter K2 pin 10 à Net-(K2-Pad10).
Connecter K2 pin 9 à VBB.
Ajout net Net-(K2-Pad6).
Connecter K2 pin 6 à Net-(K2-Pad6).
Connecter K2 pin 5 à VBB.
Métadonnées de l'unité K2 mises à jour.
Ajouté K3 (empreinte 'empreinte:EX2_NEC').
Change la référence schématique de REF** en K3.
Modifie valeur K3 de EX2_NEC en EX2-2U1S.
Mise à jour K3 association de symbole de  à /e1c4246c-006c-4214-9166-e3ac58f2a3af.
Mise a Jour des Champs de K3.
Mis à jour K3 nom de feuille en /.
Mis à jour K3 fichier de feuille en caculateur.kicad_sch.
Filtres d'empreinte K3 mis à jour en 'EX2_NEC'.
Connecter K3 pin 9 à VBB.
Ajout net Net-(K3-Pad8).
Connecter K3 pin 8 à Net-(K3-Pad8).
Connecter K3 pin 5 à VBB.
Ajout net Net-(K3-Pad2).
Connecter K3 pin 2 à Net-(K3-Pad2).
Ajout net Net-(K3-Pad3).
Connecter K3 pin 3 à Net-(K3-Pad3).
Ajout net Net-(K3-Pad6).
Connecter K3 pin 6 à Net-(K3-Pad6).
Ajout net Net-(K3-Pad7).
Connecter K3 pin 7 à Net-(K3-Pad7).
Connecter K3 pin 4 à Net-(K2-Pad10).
Connecter K3 pin 10 à Net-(K2-Pad10).
Ajout net Net-(K3-Pad1).
Connecter K3 pin 1 à Net-(K3-Pad1).
Métadonnées de l'unité K3 mises à jour.
Ajouté Q1 (empreinte 'Package_TO_SOT_SMD:SOT-23').
Change la référence schématique de REF** en Q1.
Modifie valeur Q1 de SOT-23 en AO3400A.
Mise à jour Q1 association de symbole de  à /8fb4cdac-9645-4e89-a0e2-a0f02d210195.
Mise a Jour des Champs de Q1.
Mis à jour Q1 nom de feuille en /.
Mis à jour Q1 fichier de feuille en caculateur.kicad_sch.
Filtres d'empreinte Q1 mis à jour en 'SOT?23*'.
Connecter Q1 pin 2 à GND.
Ajout net Net-(Q1-G).
Connecter Q1 pin 1 à Net-(Q1-G).
Connecter Q1 pin 3 à Net-(D5-A).
Métadonnées de l'unité Q1 mises à jour.
Ajouté R1 (empreinte 'Resistor_SMD:R_0805_2012Metric_Pad1.20x1.40mm_HandSolder').
Change la référence schématique de REF** en R1.
Modifie valeur R1 de R_0805_2012Metric_Pad1.20x1.40mm_HandSolder en 1,5kohm.
Mise à jour R1 association de symbole de  à /45a87946-b584-4363-ad0e-6f210c6f5099.
Mise a Jour des Champs de R1.
Mis à jour R1 nom de feuille en /.
Mis à jour R1 fichier de feuille en caculateur.kicad_sch.
Filtres d'empreinte R1 mis à jour en 'R_*'.
Ajout net Net-(R1-Pad1).
Connecter R1 pin 1 à Net-(R1-Pad1).
Ajout net Net-(R1-Pad2).
Connecter R1 pin 2 à Net-(R1-Pad2).
Métadonnées de l'unité R1 mises à jour.
Ajouté R2 (empreinte 'Resistor_SMD:R_0805_2012Metric_Pad1.20x1.40mm_HandSolder').
Change la référence schématique de REF** en R2.
Modifie valeur R2 de R_0805_2012Metric_Pad1.20x1.40mm_HandSolder en 1,5kohm.
Mise à jour R2 association de symbole de  à /84330283-7268-4156-847a-50051ae1adef.
Mise a Jour des Champs de R2.
Mis à jour R2 nom de feuille en /.
Mis à jour R2 fichier de feuille en caculateur.kicad_sch.
Filtres d'empreinte R2 mis à jour en 'R_*'.
Ajout net Net-(R2-Pad1).
Connecter R2 pin 1 à Net-(R2-Pad1).
Ajout net Net-(R2-Pad2).
Connecter R2 pin 2 à Net-(R2-Pad2).
Métadonnées de l'unité R2 mises à jour.
Ajouté R3 (empreinte 'Resistor_SMD:R_0805_2012Metric_Pad1.20x1.40mm_HandSolder').
Change la référence schématique de REF** en R3.
Modifie valeur R3 de R_0805_2012Metric_Pad1.20x1.40mm_HandSolder en 1,5kohm.
Mise à jour R3 association de symbole de  à /de1885c9-601a-4fc8-ba58-e53dbcb1245e.
Mise a Jour des Champs de R3.
Mis à jour R3 nom de feuille en /.
Mis à jour R3 fichier de feuille en caculateur.kicad_sch.
Filtres d'empreinte R3 mis à jour en 'R_*'.
Ajout net Net-(R3-Pad1).
Connecter R3 pin 1 à Net-(R3-Pad1).
Ajout net Net-(R3-Pad2).
Connecter R3 pin 2 à Net-(R3-Pad2).
Métadonnées de l'unité R3 mises à jour.
Ajouté R4 (empreinte 'Resistor_SMD:R_0805_2012Metric_Pad1.20x1.40mm_HandSolder').
Change la référence schématique de REF** en R4.
Modifie valeur R4 de R_0805_2012Metric_Pad1.20x1.40mm_HandSolder en 1,5kohm.
Mise à jour R4 association de symbole de  à /ff28c611-e9bb-424f-9a13-4589676bd2b7.
Mise a Jour des Champs de R4.
Mis à jour R4 nom de feuille en /.
Mis à jour R4 fichier de feuille en caculateur.kicad_sch.
Filtres d'empreinte R4 mis à jour en 'R_*'.
Ajout net Net-(R4-Pad2).
Connecter R4 pin 2 à Net-(R4-Pad2).
Ajout net Net-(R4-Pad1).
Connecter R4 pin 1 à Net-(R4-Pad1).
Métadonnées de l'unité R4 mises à jour.
Ajouté R5 (empreinte 'Resistor_SMD:R_0805_2012Metric_Pad1.20x1.40mm_HandSolder').
Change la référence schématique de REF** en R5.
Modifie valeur R5 de R_0805_2012Metric_Pad1.20x1.40mm_HandSolder en 10kohm.
Mise à jour R5 association de symbole de  à /fef17bda-cf55-4c6a-b5eb-de64a484f06e.
Mise a Jour des Champs de R5.
Mis à jour R5 nom de feuille en /.
Mis à jour R5 fichier de feuille en caculateur.kicad_sch.
Filtres d'empreinte R5 mis à jour en 'R_*'.
Ajout net Net-(R5-Pad2).
Connecter R5 pin 2 à Net-(R5-Pad2).
Ajout net Net-(R5-Pad1).
Connecter R5 pin 1 à Net-(R5-Pad1).
Métadonnées de l'unité R5 mises à jour.
Ajouté R6 (empreinte 'Resistor_SMD:R_0805_2012Metric_Pad1.20x1.40mm_HandSolder').
Change la référence schématique de REF** en R6.
Modifie valeur R6 de R_0805_2012Metric_Pad1.20x1.40mm_HandSolder en 10kohm.
Mise à jour R6 association de symbole de  à /68573149-b811-4ac3-aa5e-edca478eb0dc.
Mise a Jour des Champs de R6.
Mis à jour R6 nom de feuille en /.
Mis à jour R6 fichier de feuille en caculateur.kicad_sch.
Ajout net Net-(R6-Pad2).
Connecter R6 pin 2 à Net-(R6-Pad2).
Ajout net Net-(R6-Pad1).
Connecter R6 pin 1 à Net-(R6-Pad1).
Métadonnées de l'unité R6 mises à jour.
Ajouté R7 (empreinte 'Resistor_SMD:R_0805_2012Metric_Pad1.20x1.40mm_HandSolder').
Change la référence schématique de REF** en R7.
Modifie valeur R7 de R_0805_2012Metric_Pad1.20x1.40mm_HandSolder en 10kohm.
Mise à jour R7 association de symbole de  à /69427d50-f19e-46a4-8910-095126e4f92e.
Mise a Jour des Champs de R7.
Mis à jour R7 nom de feuille en /.
Mis à jour R7 fichier de feuille en caculateur.kicad_sch.
Filtres d'empreinte R7 mis à jour en 'R_*'.
Ajout net Net-(R7-Pad1).
Connecter R7 pin 1 à Net-(R7-Pad1).
Ajout net Net-(R7-Pad2).
Connecter R7 pin 2 à Net-(R7-Pad2).
Métadonnées de l'unité R7 mises à jour.
Ajouté R8 (empreinte 'Resistor_SMD:R_0805_2012Metric_Pad1.20x1.40mm_HandSolder').
Change la référence schématique de REF** en R8.
Modifie valeur R8 de R_0805_2012Metric_Pad1.20x1.40mm_HandSolder en 10kohm.
Mise à jour R8 association de symbole de  à /184e7404-61d2-49e9-bbd2-138125b39833.
Mise a Jour des Champs de R8.
Mis à jour R8 nom de feuille en /.
Mis à jour R8 fichier de feuille en caculateur.kicad_sch.
Filtres d'empreinte R8 mis à jour en 'R_*'.
Ajout net Net-(R8-Pad2).
Connecter R8 pin 2 à Net-(R8-Pad2).
Ajout net Net-(R8-Pad1).
Connecter R8 pin 1 à Net-(R8-Pad1).
Métadonnées de l'unité R8 mises à jour.
Ajouté R9 (empreinte 'Resistor_SMD:R_0805_2012Metric_Pad1.20x1.40mm_HandSolder').
Change la référence schématique de REF** en R9.
Modifie valeur R9 de R_0805_2012Metric_Pad1.20x1.40mm_HandSolder en 10kohm.
Mise à jour R9 association de symbole de  à /4578ac1b-2374-4f0c-8371-830e9c352212.
Mise a Jour des Champs de R9.
Mis à jour R9 nom de feuille en /.
Mis à jour R9 fichier de feuille en caculateur.kicad_sch.
Filtres d'empreinte R9 mis à jour en 'R_*'.
Connecter R9 pin 2 à GND.
Ajout net Net-(U2-BOOT0).
Connecter R9 pin 1 à Net-(U2-BOOT0).
Métadonnées de l'unité R9 mises à jour.
Ajouté R10 (empreinte 'Resistor_SMD:R_0805_2012Metric_Pad1.20x1.40mm_HandSolder').
Change la référence schématique de REF** en R10.
Modifie valeur R10 de R_0805_2012Metric_Pad1.20x1.40mm_HandSolder en 10kohm.
Mise à jour R10 association de symbole de  à /89c60d13-3545-4dec-b0df-9d5d2abf9be0.
Mise a Jour des Champs de R10.
Mis à jour R10 nom de feuille en /.
Mis à jour R10 fichier de feuille en caculateur.kicad_sch.
Filtres d'empreinte R10 mis à jour en 'R_*'.
Ajout net Net-(R10-Pad2).
Connecter R10 pin 2 à Net-(R10-Pad2).
Ajout net Net-(R10-Pad1).
Connecter R10 pin 1 à Net-(R10-Pad1).
Métadonnées de l'unité R10 mises à jour.
Ajouté R11 (empreinte 'Resistor_SMD:R_0805_2012Metric_Pad1.20x1.40mm_HandSolder').
Change la référence schématique de REF** en R11.
Modifie valeur R11 de R_0805_2012Metric_Pad1.20x1.40mm_HandSolder en 10kohm.
Mise à jour R11 association de symbole de  à /25e357eb-c755-430d-a85d-bc1875d686f9.
Mise a Jour des Champs de R11.
Mis à jour R11 nom de feuille en /.
Mis à jour R11 fichier de feuille en caculateur.kicad_sch.
Filtres d'empreinte R11 mis à jour en 'R_*'.
Ajout net Net-(R11-Pad2).
Connecter R11 pin 2 à Net-(R11-Pad2).
Ajout net Net-(R11-Pad1).
Connecter R11 pin 1 à Net-(R11-Pad1).
Métadonnées de l'unité R11 mises à jour.
Ajouté R12 (empreinte 'Resistor_SMD:R_0805_2012Metric_Pad1.20x1.40mm_HandSolder').
Change la référence schématique de REF** en R12.
Modifie valeur R12 de R_0805_2012Metric_Pad1.20x1.40mm_HandSolder en 10kohm.
Mise à jour R12 association de symbole de  à /d90954df-8209-41fb-9b08-9653d1f171c9.
Mise a Jour des Champs de R12.
Mis à jour R12 nom de feuille en /.
Mis à jour R12 fichier de feuille en caculateur.kicad_sch.
Filtres d'empreinte R12 mis à jour en 'R_*'.
Ajout net Net-(R12-Pad1).
Connecter R12 pin 1 à Net-(R12-Pad1).
Ajout net Net-(R12-Pad2).
Connecter R12 pin 2 à Net-(R12-Pad2).
Métadonnées de l'unité R12 mises à jour.
Ajouté R13 (empreinte 'Resistor_SMD:R_0805_2012Metric_Pad1.20x1.40mm_HandSolder').
Change la référence schématique de REF** en R13.
Modifie valeur R13 de R_0805_2012Metric_Pad1.20x1.40mm_HandSolder en 10kohm.
Mise à jour R13 association de symbole de  à /3c863b7d-a999-4628-8277-8faf578e8d84.
Mise a Jour des Champs de R13.
Mis à jour R13 nom de feuille en /.
Mis à jour R13 fichier de feuille en caculateur.kicad_sch.
Filtres d'empreinte R13 mis à jour en 'R_*'.
Ajout net Net-(R13-Pad2).
Connecter R13 pin 2 à Net-(R13-Pad2).
Ajout net Net-(R13-Pad1).
Connecter R13 pin 1 à Net-(R13-Pad1).
Métadonnées de l'unité R13 mises à jour.
Ajouté R14 (empreinte 'Resistor_SMD:R_0805_2012Metric_Pad1.20x1.40mm_HandSolder').
Change la référence schématique de REF** en R14.
Modifie valeur R14 de R_0805_2012Metric_Pad1.20x1.40mm_HandSolder en 1,5kohm.
Mise à jour R14 association de symbole de  à /233ba6c8-9dcd-43b2-b0a4-52d5354027c2.
Mise a Jour des Champs de R14.
Mis à jour R14 nom de feuille en /.
Mis à jour R14 fichier de feuille en caculateur.kicad_sch.
Filtres d'empreinte R14 mis à jour en 'R_*'.
Ajout net Net-(R14-Pad1).
Connecter R14 pin 1 à Net-(R14-Pad1).
Ajout net Net-(R14-Pad2).
Connecter R14 pin 2 à Net-(R14-Pad2).
Métadonnées de l'unité R14 mises à jour.
Ajouté R15 (empreinte 'Resistor_SMD:R_0805_2012Metric_Pad1.20x1.40mm_HandSolder').
Change la référence schématique de REF** en R15.
Modifie valeur R15 de R_0805_2012Metric_Pad1.20x1.40mm_HandSolder en 1,5kohm.
Mise à jour R15 association de symbole de  à /cf8e7af7-dd92-4007-b9a1-e05cdf84dcd8.
Mise a Jour des Champs de R15.
Mis à jour R15 nom de feuille en /.
Mis à jour R15 fichier de feuille en caculateur.kicad_sch.
Filtres d'empreinte R15 mis à jour en 'R_*'.
Connecter R15 pin 1 à GND.
Ajout net Net-(R15-Pad2).
Connecter R15 pin 2 à Net-(R15-Pad2).
Métadonnées de l'unité R15 mises à jour.
Ajouté R16 (empreinte 'Resistor_SMD:R_0805_2012Metric_Pad1.20x1.40mm_HandSolder').
Change la référence schématique de REF** en R16.
Modifie valeur R16 de R_0805_2012Metric_Pad1.20x1.40mm_HandSolder en 1,5kohm.
Mise à jour R16 association de symbole de  à /ecc6be63-bd47-4889-8477-20bada4dd86a.
Mise a Jour des Champs de R16.
Mis à jour R16 nom de feuille en /.
Mis à jour R16 fichier de feuille en caculateur.kicad_sch.
Filtres d'empreinte R16 mis à jour en 'R_*'.
Ajout net Net-(R16-Pad1).
Connecter R16 pin 1 à Net-(R16-Pad1).
Ajout net Net-(R16-Pad2).
Connecter R16 pin 2 à Net-(R16-Pad2).
Métadonnées de l'unité R16 mises à jour.
Ajouté R17 (empreinte 'Resistor_SMD:R_0805_2012Metric_Pad1.20x1.40mm_HandSolder').
Change la référence schématique de REF** en R17.
Modifie valeur R17 de R_0805_2012Metric_Pad1.20x1.40mm_HandSolder en 1,5kohm.
Mise à jour R17 association de symbole de  à /8175423c-54cb-4c81-8eea-ac55e22317fe.
Mise a Jour des Champs de R17.
Mis à jour R17 nom de feuille en /.
Mis à jour R17 fichier de feuille en caculateur.kicad_sch.
Filtres d'empreinte R17 mis à jour en 'R_*'.
Ajout net Net-(R17-Pad2).
Connecter R17 pin 2 à Net-(R17-Pad2).
Ajout net Net-(R17-Pad1).
Connecter R17 pin 1 à Net-(R17-Pad1).
Métadonnées de l'unité R17 mises à jour.
Ajouté R18 (empreinte 'Resistor_SMD:R_0805_2012Metric_Pad1.20x1.40mm_HandSolder').
Change la référence schématique de REF** en R18.
Modifie valeur R18 de R_0805_2012Metric_Pad1.20x1.40mm_HandSolder en 1,5kohm.
Mise à jour R18 association de symbole de  à /1fbb4a7f-13c3-4999-a91f-5f5a9a3c232b.
Mise a Jour des Champs de R18.
Mis à jour R18 nom de feuille en /.
Mis à jour R18 fichier de feuille en caculateur.kicad_sch.
Filtres d'empreinte R18 mis à jour en 'R_*'.
Ajout net Net-(R18-Pad2).
Connecter R18 pin 2 à Net-(R18-Pad2).
Ajout net Net-(R18-Pad1).
Connecter R18 pin 1 à Net-(R18-Pad1).
Métadonnées de l'unité R18 mises à jour.
Ajouté R19 (empreinte 'Resistor_SMD:R_0805_2012Metric_Pad1.20x1.40mm_HandSolder').
Change la référence schématique de REF** en R19.
Modifie valeur R19 de R_0805_2012Metric_Pad1.20x1.40mm_HandSolder en 1,5kohm.
Mise à jour R19 association de symbole de  à /8afc9bad-1bde-4c98-933b-6c7eab7a2bfd.
Mise a Jour des Champs de R19.
Mis à jour R19 nom de feuille en /.
Mis à jour R19 fichier de feuille en caculateur.kicad_sch.
Filtres d'empreinte R19 mis à jour en 'R_*'.
Ajout net Net-(R19-Pad1).
Connecter R19 pin 1 à Net-(R19-Pad1).
Ajout net Net-(R19-Pad2).
Connecter R19 pin 2 à Net-(R19-Pad2).
Métadonnées de l'unité R19 mises à jour.
Ajouté R20 (empreinte 'Resistor_SMD:R_0805_2012Metric_Pad1.20x1.40mm_HandSolder').
Change la référence schématique de REF** en R20.
Modifie valeur R20 de R_0805_2012Metric_Pad1.20x1.40mm_HandSolder en 1,5kohm.
Mise à jour R20 association de symbole de  à /240784ab-dbdb-401c-a566-5ca613c87f6d.
Mise a Jour des Champs de R20.
Mis à jour R20 nom de feuille en /.
Mis à jour R20 fichier de feuille en caculateur.kicad_sch.
Filtres d'empreinte R20 mis à jour en 'R_*'.
Ajout net Net-(R20-Pad2).
Connecter R20 pin 2 à Net-(R20-Pad2).
Ajout net Net-(R20-Pad1).
Connecter R20 pin 1 à Net-(R20-Pad1).
Métadonnées de l'unité R20 mises à jour.
Ajouté R21 (empreinte 'Resistor_SMD:R_0805_2012Metric_Pad1.20x1.40mm_HandSolder').
Change la référence schématique de REF** en R21.
Modifie valeur R21 de R_0805_2012Metric_Pad1.20x1.40mm_HandSolder en 1,5kohm.
Mise à jour R21 association de symbole de  à /dd70a4d5-85c3-4911-be66-e6d0afcc263b.
Mise a Jour des Champs de R21.
Mis à jour R21 nom de feuille en /.
Mis à jour R21 fichier de feuille en caculateur.kicad_sch.
Filtres d'empreinte R21 mis à jour en 'R_*'.
Ajout net Net-(R21-Pad2).
Connecter R21 pin 2 à Net-(R21-Pad2).
Connecter R21 pin 1 à GND.
Métadonnées de l'unité R21 mises à jour.
Ajouté R22 (empreinte 'Resistor_SMD:R_0805_2012Metric_Pad1.20x1.40mm_HandSolder').
Change la référence schématique de REF** en R22.
Modifie valeur R22 de R_0805_2012Metric_Pad1.20x1.40mm_HandSolder en 10kohm.
Mise à jour R22 association de symbole de  à /ca245dd9-7a76-4787-acba-6e71bc2606dc.
Mise a Jour des Champs de R22.
Mis à jour R22 nom de feuille en /.
Mis à jour R22 fichier de feuille en caculateur.kicad_sch.
Filtres d'empreinte R22 mis à jour en 'R_*'.
Ajout net Net-(R22-Pad2).
Connecter R22 pin 2 à Net-(R22-Pad2).
Ajout net Net-(R22-Pad1).
Connecter R22 pin 1 à Net-(R22-Pad1).
Métadonnées de l'unité R22 mises à jour.
Ajouté R23 (empreinte 'Resistor_SMD:R_0805_2012Metric_Pad1.20x1.40mm_HandSolder').
Filtres d'empreinte R6 mis à jour en 'R_*'.
Modifie valeur R23 de R_0805_2012Metric_Pad1.20x1.40mm_HandSolder en 10kohm.
Mise à jour R23 association de symbole de  à /76aabaa1-5d82-46bf-b831-190af8096a1d.
Mise a Jour des Champs de R23.
Mis à jour R23 nom de feuille en /.
Mis à jour R23 fichier de feuille en caculateur.kicad_sch.
Filtres d'empreinte R23 mis à jour en 'R_*'.
Ajout net Net-(R23-Pad2).
Connecter R23 pin 2 à Net-(R23-Pad2).
Ajout net Net-(R23-Pad1).
Connecter R23 pin 1 à Net-(R23-Pad1).
Métadonnées de l'unité R23 mises à jour.
Ajouté C1 (empreinte 'Capacitor_SMD:CP_Elec_8x10.5').
Ajouté R24 (empreinte 'Resistor_SMD:R_0805_2012Metric_Pad1.20x1.40mm_HandSolder').
Change la référence schématique de REF** en R24.
Modifie valeur R24 de R_0805_2012Metric_Pad1.20x1.40mm_HandSolder en 10kohm.
Mise à jour R24 association de symbole de  à /73cb7d44-9174-455c-a5d7-a79cd1946e2b.
Mise a Jour des Champs de R24.
Mis à jour R24 nom de feuille en /.
Mis à jour R24 fichier de feuille en caculateur.kicad_sch.
Filtres d'empreinte R24 mis à jour en 'R_*'.
Ajout net Net-(R24-Pad1).
Connecter R24 pin 1 à Net-(R24-Pad1).
Ajout net Net-(R24-Pad2).
Connecter R24 pin 2 à Net-(R24-Pad2).
Métadonnées de l'unité R24 mises à jour.
Change la référence schématique de REF** en C1.
Ajouté R25 (empreinte 'Resistor_SMD:R_0805_2012Metric_Pad1.20x1.40mm_HandSolder').
Change la référence schématique de REF** en R25.
Modifie valeur R25 de R_0805_2012Metric_Pad1.20x1.40mm_HandSolder en 10kohm.
Mise à jour R25 association de symbole de  à /12df243e-da8f-49ac-bb69-12ffb294fcd3.
Mise a Jour des Champs de R25.
Mis à jour R25 nom de feuille en /.
Mis à jour R25 fichier de feuille en caculateur.kicad_sch.
Filtres d'empreinte R25 mis à jour en 'R_*'.
Ajout net Net-(R25-Pad2).
Connecter R25 pin 2 à Net-(R25-Pad2).
Ajout net Net-(R25-Pad1).
Connecter R25 pin 1 à Net-(R25-Pad1).
Métadonnées de l'unité R25 mises à jour.
Modifie valeur C1 de CP_Elec_8x10.5 en C_Polarized 100µf.
Ajouté R26 (empreinte 'Resistor_SMD:R_1206_3216Metric').
Change la référence schématique de REF** en R26.
Modifie valeur R26 de R_1206_3216Metric en 4,7kohm.
Mise à jour R26 association de symbole de  à /3e023ac8-3383-4769-8be4-2fe64525bbd0.
Mise a Jour des Champs de R26.
Mis à jour R26 nom de feuille en /.
Mis à jour R26 fichier de feuille en caculateur.kicad_sch.
Filtres d'empreinte R26 mis à jour en 'R_*'.
Connecter R26 pin 2 à Net-(D3-K).
Ajout net Net-(R26-Pad1).
Connecter R26 pin 1 à Net-(R26-Pad1).
Métadonnées de l'unité R26 mises à jour.
Mise à jour C1 association de symbole de  à /95dfceb8-6187-48ff-bd67-bec299ef00c4.
Ajouté R27 (empreinte 'Resistor_SMD:R_1206_3216Metric').
Change la référence schématique de REF** en R27.
Modifie valeur R27 de R_1206_3216Metric en 1kohm.
Mise à jour R27 association de symbole de  à /fabb2749-be9b-4124-9d88-6ac65c17006a.
Mise a Jour des Champs de R27.
Mis à jour R27 nom de feuille en /.
Mis à jour R27 fichier de feuille en caculateur.kicad_sch.
Filtres d'empreinte R27 mis à jour en 'R_*'.
Ajout net Net-(R27-Pad2).
Connecter R27 pin 2 à Net-(R27-Pad2).
Connecter R27 pin 1 à Net-(D3-K).
Métadonnées de l'unité R27 mises à jour.
Mise a Jour des Champs de C1.
Ajouté R28 (empreinte 'Resistor_SMD:R_0805_2012Metric_Pad1.20x1.40mm_HandSolder').
Change la référence schématique de REF** en R28.
Modifie valeur R28 de R_0805_2012Metric_Pad1.20x1.40mm_HandSolder en 1,5kohm.
Mise à jour R28 association de symbole de  à /81a3120c-6d9b-4b17-aae6-02d261cf772e.
Mise a Jour des Champs de R28.
Mis à jour R28 nom de feuille en /.
Mis à jour R28 fichier de feuille en caculateur.kicad_sch.
Filtres d'empreinte R28 mis à jour en 'R_*'.
Ajout net Net-(R28-Pad2).
Connecter R28 pin 2 à Net-(R28-Pad2).
Ajout net Net-(R28-Pad1).
Connecter R28 pin 1 à Net-(R28-Pad1).
Métadonnées de l'unité R28 mises à jour.
Mis à jour C1 nom de feuille en /.
Ajouté R29 (empreinte 'Resistor_SMD:R_0805_2012Metric_Pad1.20x1.40mm_HandSolder').
Change la référence schématique de REF** en R29.
Modifie valeur R29 de R_0805_2012Metric_Pad1.20x1.40mm_HandSolder en 1,5kohm.
Mise à jour R29 association de symbole de  à /7c5ff86f-0de5-4555-b7cd-cb76f5070f85.
Mise a Jour des Champs de R29.
Mis à jour R29 nom de feuille en /.
Mis à jour R29 fichier de feuille en caculateur.kicad_sch.
Filtres d'empreinte R29 mis à jour en 'R_*'.
Ajout net Net-(R29-Pad2).
Connecter R29 pin 2 à Net-(R29-Pad2).
Ajout net Net-(R29-Pad1).
Connecter R29 pin 1 à Net-(R29-Pad1).
Métadonnées de l'unité R29 mises à jour.
Mis à jour C1 fichier de feuille en caculateur.kicad_sch.
Ajouté R30 (empreinte 'Resistor_SMD:R_0805_2012Metric_Pad1.20x1.40mm_HandSolder').
Change la référence schématique de REF** en R30.
Modifie valeur R30 de R_0805_2012Metric_Pad1.20x1.40mm_HandSolder en 1,5kohm.
Mise à jour R30 association de symbole de  à /bcff10ec-aa94-4f33-8c95-5a6cc7557224.
Mise a Jour des Champs de R30.
Mis à jour R30 nom de feuille en /.
Mis à jour R30 fichier de feuille en caculateur.kicad_sch.
Filtres d'empreinte R30 mis à jour en 'R_*'.
Ajout net Net-(R30-Pad2).
Connecter R30 pin 2 à Net-(R30-Pad2).
Ajout net Net-(R30-Pad1).
Connecter R30 pin 1 à Net-(R30-Pad1).
Métadonnées de l'unité R30 mises à jour.
Filtres d'empreinte C1 mis à jour en 'CP_*'.
Ajouté R31 (empreinte 'Resistor_SMD:R_0805_2012Metric_Pad1.20x1.40mm_HandSolder').
Change la référence schématique de REF** en R31.
Modifie valeur R31 de R_0805_2012Metric_Pad1.20x1.40mm_HandSolder en 1,5kohm.
Mise à jour R31 association de symbole de  à /ea8446de-7f92-4ed1-882c-beb48f86e254.
Mise a Jour des Champs de R31.
Mis à jour R31 nom de feuille en /.
Mis à jour R31 fichier de feuille en caculateur.kicad_sch.
Filtres d'empreinte R31 mis à jour en 'R_*'.
Ajout net Net-(R31-Pad1).
Connecter R31 pin 1 à Net-(R31-Pad1).
Ajout net Net-(R31-Pad2).
Connecter R31 pin 2 à Net-(R31-Pad2).
Métadonnées de l'unité R31 mises à jour.
Ajout net Net-(U1-Vin).
Ajouté R32 (empreinte 'Resistor_SMD:R_0805_2012Metric_Pad1.20x1.40mm_HandSolder').
Change la référence schématique de REF** en R32.
Modifie valeur R32 de R_0805_2012Metric_Pad1.20x1.40mm_HandSolder en 10kohm.
Mise à jour R32 association de symbole de  à /b45d3a6a-14e2-49b7-bfa1-c6a54a0b8e68.
Mise a Jour des Champs de R32.
Mis à jour R32 nom de feuille en /.
Mis à jour R32 fichier de feuille en caculateur.kicad_sch.
Filtres d'empreinte R32 mis à jour en 'R_*'.
Ajout net Net-(R32-Pad2).
Connecter R32 pin 2 à Net-(R32-Pad2).
Ajout net Net-(R32-Pad1).
Connecter R32 pin 1 à Net-(R32-Pad1).
Métadonnées de l'unité R32 mises à jour.
Connecter C1 pin 1 à Net-(U1-Vin).
Ajouté R33 (empreinte 'Resistor_SMD:R_0805_2012Metric_Pad1.20x1.40mm_HandSolder').
Change la référence schématique de REF** en R33.
Modifie valeur R33 de R_0805_2012Metric_Pad1.20x1.40mm_HandSolder en 10kohm.
Mise à jour R33 association de symbole de  à /65f36ce4-e4ee-4831-81eb-5d8407524f5a.
Mise a Jour des Champs de R33.
Mis à jour R33 nom de feuille en /.
Mis à jour R33 fichier de feuille en caculateur.kicad_sch.
Filtres d'empreinte R33 mis à jour en 'R_*'.
Ajout net Net-(R33-Pad1).
Connecter R33 pin 1 à Net-(R33-Pad1).
Ajout net Net-(R33-Pad2).
Connecter R33 pin 2 à Net-(R33-Pad2).
Métadonnées de l'unité R33 mises à jour.
Connecter C1 pin 2 à GND.
Ajouté R34 (empreinte 'Resistor_SMD:R_0805_2012Metric_Pad1.20x1.40mm_HandSolder').
Change la référence schématique de REF** en R34.
Modifie valeur R34 de R_0805_2012Metric_Pad1.20x1.40mm_HandSolder en 10kohm.
Mise à jour R34 association de symbole de  à /097472ad-4fed-4541-97b4-d44f3461a95c.
Mise a Jour des Champs de R34.
Mis à jour R34 nom de feuille en /.
Mis à jour R34 fichier de feuille en caculateur.kicad_sch.
Filtres d'empreinte R34 mis à jour en 'R_*'.
Ajout net Net-(R34-Pad2).
Connecter R34 pin 2 à Net-(R34-Pad2).
Ajout net Net-(R34-Pad1).
Connecter R34 pin 1 à Net-(R34-Pad1).
Métadonnées de l'unité R34 mises à jour.
Métadonnées de l'unité C1 mises à jour.
Ajouté R35 (empreinte 'Resistor_SMD:R_0805_2012Metric_Pad1.20x1.40mm_HandSolder').
Change la référence schématique de REF** en R35.
Modifie valeur R35 de R_0805_2012Metric_Pad1.20x1.40mm_HandSolder en 10kohm.
Mise à jour R35 association de symbole de  à /11a9d921-8b1e-4c32-989e-ed2321607370.
Mise a Jour des Champs de R35.
Mis à jour R35 nom de feuille en /.
Mis à jour R35 fichier de feuille en caculateur.kicad_sch.
Filtres d'empreinte R35 mis à jour en 'R_*'.
Ajout net Net-(R35-Pad2).
Connecter R35 pin 2 à Net-(R35-Pad2).
Ajout net Net-(R35-Pad1).
Connecter R35 pin 1 à Net-(R35-Pad1).
Métadonnées de l'unité R35 mises à jour.
Ajouté C2 (empreinte 'Capacitor_SMD:C_0805_2012Metric_Pad1.18x1.45mm_HandSolder').
Ajouté R36 (empreinte 'Resistor_SMD:R_1206_3216Metric').
Change la référence schématique de REF** en R36.
Modifie valeur R36 de R_1206_3216Metric en 4,7kohm.
Mise à jour R36 association de symbole de  à /12e9d0c2-e962-42d9-95ec-265d62851e9e.
Mise a Jour des Champs de R36.
Mis à jour R36 nom de feuille en /.
Mis à jour R36 fichier de feuille en caculateur.kicad_sch.
Filtres d'empreinte R36 mis à jour en 'R_*'.
Ajout net Net-(R36-Pad1).
Connecter R36 pin 1 à Net-(R36-Pad1).
Connecter R36 pin 2 à Net-(D4-K).
Métadonnées de l'unité R36 mises à jour.
Change la référence schématique de REF** en C2.
Ajouté R37 (empreinte 'Resistor_SMD:R_1206_3216Metric').
Change la référence schématique de REF** en R37.
Modifie valeur R37 de R_1206_3216Metric en 1kohm.
Mise à jour R37 association de symbole de  à /1746c0a2-7833-41b4-9b64-32545b0ab673.
Mise a Jour des Champs de R37.
Mis à jour R37 nom de feuille en /.
Mis à jour R37 fichier de feuille en caculateur.kicad_sch.
Filtres d'empreinte R37 mis à jour en 'R_*'.
Connecter R37 pin 1 à Net-(D4-K).
Ajout net Net-(R37-Pad2).
Connecter R37 pin 2 à Net-(R37-Pad2).
Métadonnées de l'unité R37 mises à jour.
Modifie valeur C2 de C_0805_2012Metric_Pad1.18x1.45mm_HandSolder en 100nf.
Ajouté R38 (empreinte 'Resistor_SMD:R_0805_2012Metric_Pad1.20x1.40mm_HandSolder').
Change la référence schématique de REF** en R38.
Modifie valeur R38 de R_0805_2012Metric_Pad1.20x1.40mm_HandSolder en 100ohm.
Mise à jour R38 association de symbole de  à /7a518815-5031-4fb5-842e-f9a0eb99e304.
Mise a Jour des Champs de R38.
Mis à jour R38 nom de feuille en /.
Mis à jour R38 fichier de feuille en caculateur.kicad_sch.
Filtres d'empreinte R38 mis à jour en 'R_*'.
Ajout net Net-(R38-Pad2).
Connecter R38 pin 2 à Net-(R38-Pad2).
Connecter R38 pin 1 à Net-(Q1-G).
Métadonnées de l'unité R38 mises à jour.
Mise à jour C2 association de symbole de  à /d8c2316a-4b77-4aaf-886f-4d6e587ab332.
Ajouté R39 (empreinte 'Resistor_SMD:R_0805_2012Metric_Pad1.20x1.40mm_HandSolder').
Change la référence schématique de REF** en R39.
Modifie valeur R39 de R_0805_2012Metric_Pad1.20x1.40mm_HandSolder en 10kohm.
Mise à jour R39 association de symbole de  à /fea180e7-a152-4b32-8b48-3fc2842134f8.
Mise a Jour des Champs de R39.
Mis à jour R39 nom de feuille en /.
Mis à jour R39 fichier de feuille en caculateur.kicad_sch.
Filtres d'empreinte R39 mis à jour en 'R_*'.
Connecter R39 pin 2 à GND.
Connecter R39 pin 1 à Net-(Q1-G).
Métadonnées de l'unité R39 mises à jour.
Change la référence schématique de REF** en R23.
Ajouté R40 (empreinte 'Resistor_SMD:R_0805_2012Metric_Pad1.20x1.40mm_HandSolder').
Change la référence schématique de REF** en R40.
Modifie valeur R40 de R_0805_2012Metric_Pad1.20x1.40mm_HandSolder en 1kohm.
Mise à jour R40 association de symbole de  à /67d63c9d-ffd5-4caa-a07b-f1b4d679c199.
Mise a Jour des Champs de R40.
Mis à jour R40 nom de feuille en /.
Mis à jour R40 fichier de feuille en caculateur.kicad_sch.
Filtres d'empreinte R40 mis à jour en 'R_*'.
Ajout net Net-(R40-Pad1).
Connecter R40 pin 1 à Net-(R40-Pad1).
Ajout net Net-(U7-IN1).
Connecter R40 pin 2 à Net-(U7-IN1).
Métadonnées de l'unité R40 mises à jour.
Mise a Jour des Champs de C2.
Ajouté R41 (empreinte 'Resistor_SMD:R_0805_2012Metric_Pad1.20x1.40mm_HandSolder').
Change la référence schématique de REF** en R41.
Modifie valeur R41 de R_0805_2012Metric_Pad1.20x1.40mm_HandSolder en 10kohm.
Mise à jour R41 association de symbole de  à /6c6c9e20-c732-45c7-afd9-3ae7aab2b132.
Mise a Jour des Champs de R41.
Mis à jour R41 nom de feuille en /.
Mis à jour R41 fichier de feuille en caculateur.kicad_sch.
Filtres d'empreinte R41 mis à jour en 'R_*'.
Connecter R41 pin 2 à Net-(U7-IN1).
Connecter R41 pin 1 à GND.
Métadonnées de l'unité R41 mises à jour.
Mis à jour C2 nom de feuille en /.
Ajouté R42 (empreinte 'Resistor_SMD:R_0805_2012Metric_Pad1.20x1.40mm_HandSolder').
Change la référence schématique de REF** en R42.
Modifie valeur R42 de R_0805_2012Metric_Pad1.20x1.40mm_HandSolder en 1kohm.
Mise à jour R42 association de symbole de  à /8f3d027e-44f2-4bc6-acf3-c87ed16a9699.
Mise a Jour des Champs de R42.
Mis à jour R42 nom de feuille en /.
Mis à jour R42 fichier de feuille en caculateur.kicad_sch.
Filtres d'empreinte R42 mis à jour en 'R_*'.
Ajout net Net-(R42-Pad1).
Connecter R42 pin 1 à Net-(R42-Pad1).
Ajout net Net-(U7-IN2).
Connecter R42 pin 2 à Net-(U7-IN2).
Métadonnées de l'unité R42 mises à jour.
Mis à jour C2 fichier de feuille en caculateur.kicad_sch.
Ajouté R43 (empreinte 'Resistor_SMD:R_0805_2012Metric_Pad1.20x1.40mm_HandSolder').
Change la référence schématique de REF** en R43.
Modifie valeur R43 de R_0805_2012Metric_Pad1.20x1.40mm_HandSolder en 10kohm.
Mise à jour R43 association de symbole de  à /1b987984-4d06-45e0-a8a7-5078fdc4a7ce.
Mise a Jour des Champs de R43.
Mis à jour R43 nom de feuille en /.
Mis à jour R43 fichier de feuille en caculateur.kicad_sch.
Filtres d'empreinte R43 mis à jour en 'R_*'.
Connecter R43 pin 1 à Net-(U7-IN2).
Connecter R43 pin 2 à GND.
Métadonnées de l'unité R43 mises à jour.
Filtres d'empreinte C2 mis à jour en 'C_*'.
Ajouté R44 (empreinte 'Resistor_SMD:R_0805_2012Metric_Pad1.20x1.40mm_HandSolder').
Change la référence schématique de REF** en R44.
Modifie valeur R44 de R_0805_2012Metric_Pad1.20x1.40mm_HandSolder en 1kohm.
Mise à jour R44 association de symbole de  à /2889c49b-0ae7-4b2f-8747-bff6784dd93c.
Mise a Jour des Champs de R44.
Mis à jour R44 nom de feuille en /.
Mis à jour R44 fichier de feuille en caculateur.kicad_sch.
Filtres d'empreinte R44 mis à jour en 'R_*'.
Ajout net Net-(U7-IN3).
Connecter R44 pin 2 à Net-(U7-IN3).
Ajout net Net-(R44-Pad1).
Connecter R44 pin 1 à Net-(R44-Pad1).
Métadonnées de l'unité R44 mises à jour.
Connecter C2 pin 2 à GND.
Ajouté R45 (empreinte 'Resistor_SMD:R_0805_2012Metric_Pad1.20x1.40mm_HandSolder').
Change la référence schématique de REF** en R45.
Modifie valeur R45 de R_0805_2012Metric_Pad1.20x1.40mm_HandSolder en 10kohm.
Mise à jour R45 association de symbole de  à /135d69ef-5423-405f-8d18-d6af3bf03ea4.
Mise a Jour des Champs de R45.
Mis à jour R45 nom de feuille en /.
Mis à jour R45 fichier de feuille en caculateur.kicad_sch.
Filtres d'empreinte R45 mis à jour en 'R_*'.
Connecter R45 pin 1 à Net-(U7-IN3).
Connecter R45 pin 2 à GND.
Métadonnées de l'unité R45 mises à jour.
Connecter C2 pin 1 à Net-(U1-Vin).
Ajouté R46 (empreinte 'Resistor_SMD:R_0805_2012Metric_Pad1.20x1.40mm_HandSolder').
Change la référence schématique de REF** en R46.
Modifie valeur R46 de R_0805_2012Metric_Pad1.20x1.40mm_HandSolder en 1kohm.
Mise à jour R46 association de symbole de  à /b8746b28-3545-4923-bf43-75025e98446f.
Mise a Jour des Champs de R46.
Mis à jour R46 nom de feuille en /.
Mis à jour R46 fichier de feuille en caculateur.kicad_sch.
Filtres d'empreinte R46 mis à jour en 'R_*'.
Connecter R46 pin 2 à GND.
Connecter R46 pin 1 à Net-(D6-A).
Métadonnées de l'unité R46 mises à jour.
Métadonnées de l'unité C2 mises à jour.
Ajouté R47 (empreinte 'Resistor_SMD:R_0805_2012Metric_Pad1.20x1.40mm_HandSolder').
Change la référence schématique de REF** en R47.
Modifie valeur R47 de R_0805_2012Metric_Pad1.20x1.40mm_HandSolder en 1kohm.
Mise à jour R47 association de symbole de  à /7403cf56-5361-476d-b86d-34b172f53a38.
Mise a Jour des Champs de R47.
Mis à jour R47 nom de feuille en /.
Mis à jour R47 fichier de feuille en caculateur.kicad_sch.
Filtres d'empreinte R47 mis à jour en 'R_*'.
Connecter R47 pin 1 à Net-(D7-A).
Connecter R47 pin 2 à GND.
Métadonnées de l'unité R47 mises à jour.
Ajouté C3 (empreinte 'Capacitor_Tantalum_SMD:CP_EIA-3216-18_Kemet-A_HandSolder').
Ajouté R48 (empreinte 'Resistor_SMD:R_0805_2012Metric_Pad1.20x1.40mm_HandSolder').
Change la référence schématique de REF** en R48.
Modifie valeur R48 de R_0805_2012Metric_Pad1.20x1.40mm_HandSolder en 1kohm.
Mise à jour R48 association de symbole de  à /11badeec-5101-46ba-9900-2c18a2e0e9a6.
Mise a Jour des Champs de R48.
Mis à jour R48 nom de feuille en /.
Mis à jour R48 fichier de feuille en caculateur.kicad_sch.
Filtres d'empreinte R48 mis à jour en 'R_*'.
Ajout net Net-(R48-Pad1).
Connecter R48 pin 1 à Net-(R48-Pad1).
Connecter R48 pin 2 à Net-(U9A-+).
Métadonnées de l'unité R48 mises à jour.
Change la référence schématique de REF** en C3.
Ajouté R49 (empreinte 'Resistor_SMD:R_0805_2012Metric_Pad1.20x1.40mm_HandSolder').
Change la référence schématique de REF** en R49.
Modifie valeur R49 de R_0805_2012Metric_Pad1.20x1.40mm_HandSolder en 5,6kohm.
Mise à jour R49 association de symbole de  à /ddff3caf-6ecf-4024-aa8e-fe2433f8bce4.
Mise a Jour des Champs de R49.
Mis à jour R49 nom de feuille en /.
Mis à jour R49 fichier de feuille en caculateur.kicad_sch.
Filtres d'empreinte R49 mis à jour en 'R_*'.
Ajout net Net-(U9A--).
Connecter R49 pin 2 à Net-(U9A--).
Ajout net Net-(R49-Pad1).
Connecter R49 pin 1 à Net-(R49-Pad1).
Métadonnées de l'unité R49 mises à jour.
Modifie valeur C3 de CP_EIA-3216-18_Kemet-A_HandSolder en C_Polarized 10µf.
Ajouté R50 (empreinte 'Resistor_SMD:R_0805_2012Metric_Pad1.20x1.40mm_HandSolder').
Change la référence schématique de REF** en R50.
Modifie valeur R50 de R_0805_2012Metric_Pad1.20x1.40mm_HandSolder en 1kohm.
Mise à jour R50 association de symbole de  à /783a632e-0090-4001-bb4b-bc42df1dbb96.
Mise a Jour des Champs de R50.
Mis à jour R50 nom de feuille en /.
Mis à jour R50 fichier de feuille en caculateur.kicad_sch.
Filtres d'empreinte R50 mis à jour en 'R_*'.
Connecter R50 pin 1 à GND.
Connecter R50 pin 2 à Net-(U9A--).
Métadonnées de l'unité R50 mises à jour.
Mise à jour C3 association de symbole de  à /3a7bd596-d433-48ff-b092-c59ad5b3ebdc.
Ajouté R51 (empreinte 'Resistor_SMD:R_0805_2012Metric_Pad1.20x1.40mm_HandSolder').
Change la référence schématique de REF** en R51.
Modifie valeur R51 de R_0805_2012Metric_Pad1.20x1.40mm_HandSolder en 1kohm.
Mise à jour R51 association de symbole de  à /7087d030-a7c7-46c5-b0f0-89c83167827d.
Mise a Jour des Champs de R51.
Mis à jour R51 nom de feuille en /.
Mis à jour R51 fichier de feuille en caculateur.kicad_sch.
Filtres d'empreinte R51 mis à jour en 'R_*'.
Connecter R51 pin 2 à Net-(R49-Pad1).
Connecter R51 pin 1 à Net-(D8-K).
Métadonnées de l'unité R51 mises à jour.
Mise a Jour des Champs de C3.
Ajouté R52 (empreinte 'Resistor_SMD:R_0805_2012Metric_Pad1.20x1.40mm_HandSolder').
Change la référence schématique de REF** en R52.
Modifie valeur R52 de R_0805_2012Metric_Pad1.20x1.40mm_HandSolder en 1kohm.
Mise à jour R52 association de symbole de  à /0f0dd23d-7a5b-491d-9632-85c508766682.
Mise a Jour des Champs de R52.
Mis à jour R52 nom de feuille en /.
Mis à jour R52 fichier de feuille en caculateur.kicad_sch.
Filtres d'empreinte R52 mis à jour en 'R_*'.
Connecter R52 pin 2 à Net-(U9B-+).
Ajout net Net-(R52-Pad1).
Connecter R52 pin 1 à Net-(R52-Pad1).
Métadonnées de l'unité R52 mises à jour.
Mis à jour C3 nom de feuille en /.
Ajouté R53 (empreinte 'Resistor_SMD:R_0805_2012Metric_Pad1.20x1.40mm_HandSolder').
Change la référence schématique de REF** en R53.
Modifie valeur R53 de R_0805_2012Metric_Pad1.20x1.40mm_HandSolder en 1kohm.
Mise à jour R53 association de symbole de  à /a08c15af-1b0c-4a46-aba6-dc3e1ddc6700.
Mise a Jour des Champs de R53.
Mis à jour R53 nom de feuille en /.
Mis à jour R53 fichier de feuille en caculateur.kicad_sch.
Filtres d'empreinte R53 mis à jour en 'R_*'.
Connecter R53 pin 1 à GND.
Ajout net Net-(U9B--).
Connecter R53 pin 2 à Net-(U9B--).
Métadonnées de l'unité R53 mises à jour.
Mis à jour C3 fichier de feuille en caculateur.kicad_sch.
Ajouté R54 (empreinte 'Resistor_SMD:R_0805_2012Metric_Pad1.20x1.40mm_HandSolder').
Change la référence schématique de REF** en R54.
Modifie valeur R54 de R_0805_2012Metric_Pad1.20x1.40mm_HandSolder en 5,6kohm.
Mise à jour R54 association de symbole de  à /ed1faacf-91b1-469e-a4f2-f3e0dcae3215.
Mise a Jour des Champs de R54.
Mis à jour R54 nom de feuille en /.
Mis à jour R54 fichier de feuille en caculateur.kicad_sch.
Filtres d'empreinte R54 mis à jour en 'R_*'.
Connecter R54 pin 2 à Net-(U9B--).
Ajout net Net-(R54-Pad1).
Connecter R54 pin 1 à Net-(R54-Pad1).
Métadonnées de l'unité R54 mises à jour.
Filtres d'empreinte C3 mis à jour en 'CP_*'.
Ajouté R55 (empreinte 'Resistor_SMD:R_0805_2012Metric_Pad1.20x1.40mm_HandSolder').
Change la référence schématique de REF** en R55.
Modifie valeur R55 de R_0805_2012Metric_Pad1.20x1.40mm_HandSolder en 1kohm.
Mise à jour R55 association de symbole de  à /3785edaa-b978-4a49-ac69-6f2bfd29f04c.
Mise a Jour des Champs de R55.
Mis à jour R55 nom de feuille en /.
Mis à jour R55 fichier de feuille en caculateur.kicad_sch.
Filtres d'empreinte R55 mis à jour en 'R_*'.
Connecter R55 pin 1 à Net-(D9-K).
Connecter R55 pin 2 à Net-(R54-Pad1).
Métadonnées de l'unité R55 mises à jour.
Ajout net Net-(U1-Vout).
Ajouté R56 (empreinte 'Resistor_SMD:R_1206_3216Metric').
Change la référence schématique de REF** en R56.
Modifie valeur R56 de R_1206_3216Metric en 27ohm.
Mise à jour R56 association de symbole de  à /13389ae4-6afd-4537-a77d-6797c6a419a4.
Mise a Jour des Champs de R56.
Mis à jour R56 nom de feuille en /.
Mis à jour R56 fichier de feuille en caculateur.kicad_sch.
Filtres d'empreinte R56 mis à jour en 'R_*'.
Ajout net Net-(R56-Pad1).
Connecter R56 pin 1 à Net-(R56-Pad1).
Ajout net Net-(U11-O7).
Connecter R56 pin 2 à Net-(U11-O7).
Métadonnées de l'unité R56 mises à jour.
Connecter C3 pin 1 à Net-(U1-Vout).
Ajouté R57 (empreinte 'Resistor_SMD:R_1206_3216Metric').
Change la référence schématique de REF** en R57.
Modifie valeur R57 de R_1206_3216Metric en 27ohm.
Mise à jour R57 association de symbole de  à /beed3320-8ae0-485b-9d3d-3c737694f6de.
Mise a Jour des Champs de R57.
Mis à jour R57 nom de feuille en /.
Mis à jour R57 fichier de feuille en caculateur.kicad_sch.
Filtres d'empreinte R57 mis à jour en 'R_*'.
Ajout net Net-(U11-O8).
Connecter R57 pin 2 à Net-(U11-O8).
Ajout net Net-(R57-Pad1).
Connecter R57 pin 1 à Net-(R57-Pad1).
Métadonnées de l'unité R57 mises à jour.
Connecter C3 pin 2 à GND.
Ajouté R_Shunt_1 (empreinte 'Resistor_SMD:R_Shunt_Vishay_WSR2_WSR3').
Change la référence schématique de REF** en R_Shunt_1.
Modifie valeur R_Shunt_1 de R_Shunt_Vishay_WSR2_WSR3 en 0,025ohm.
Mise à jour R_Shunt_1 association de symbole de  à /be22c439-3a72-4dfd-a98d-8adf08d54b44.
Mise a Jour des Champs de R_Shunt_1.
Mis à jour R_Shunt_1 nom de feuille en /.
Mis à jour R_Shunt_1 fichier de feuille en caculateur.kicad_sch.
Filtres d'empreinte R_Shunt_1 mis à jour en 'R_*'.
Connecter R_Shunt_1 pin 1 à GNDPWR.
Connecter R_Shunt_1 pin 2 à Net-(K1-Pad10).
Métadonnées de l'unité R_Shunt_1 mises à jour.
Métadonnées de l'unité C3 mises à jour.
Ajouté R_Shunt_2 (empreinte 'Resistor_SMD:R_Shunt_Vishay_WSR2_WSR3').
Change la référence schématique de REF** en R_Shunt_2.
Modifie valeur R_Shunt_2 de R_Shunt_Vishay_WSR2_WSR3 en 0,025ohm.
Mise à jour R_Shunt_2 association de symbole de  à /e8fa3563-f5af-460c-9dfb-87f3d499e20a.
Mise a Jour des Champs de R_Shunt_2.
Mis à jour R_Shunt_2 nom de feuille en /.
Mis à jour R_Shunt_2 fichier de feuille en caculateur.kicad_sch.
Filtres d'empreinte R_Shunt_2 mis à jour en 'R_*'.
Connecter R_Shunt_2 pin 1 à GNDPWR.
Connecter R_Shunt_2 pin 2 à Net-(K1-Pad10).
Métadonnées de l'unité R_Shunt_2 mises à jour.
Ajouté C4 (empreinte 'Capacitor_SMD:C_0805_2012Metric_Pad1.18x1.45mm_HandSolder').
Ajouté R_Shunt_3 (empreinte 'Resistor_SMD:R_Shunt_Vishay_WSR2_WSR3').
Change la référence schématique de REF** en R_Shunt_3.
Modifie valeur R_Shunt_3 de R_Shunt_Vishay_WSR2_WSR3 en 0,025ohm.
Mise à jour R_Shunt_3 association de symbole de  à /04dc6743-2730-4523-bf65-637391b9162f.
Mise a Jour des Champs de R_Shunt_3.
Mis à jour R_Shunt_3 nom de feuille en /.
Mis à jour R_Shunt_3 fichier de feuille en caculateur.kicad_sch.
Filtres d'empreinte R_Shunt_3 mis à jour en 'R_*'.
Connecter R_Shunt_3 pin 1 à GNDPWR.
Connecter R_Shunt_3 pin 2 à Net-(K2-Pad10).
Métadonnées de l'unité R_Shunt_3 mises à jour.
Change la référence schématique de REF** en C4.
Ajouté R_Shunt_4 (empreinte 'Resistor_SMD:R_Shunt_Vishay_WSR2_WSR3').
Change la référence schématique de REF** en R_Shunt_4.
Modifie valeur R_Shunt_4 de R_Shunt_Vishay_WSR2_WSR3 en 0,025ohm.
Mise à jour R_Shunt_4 association de symbole de  à /2715dc57-1a70-4501-8c59-d8806a620c78.
Mise a Jour des Champs de R_Shunt_4.
Mis à jour R_Shunt_4 nom de feuille en /.
Mis à jour R_Shunt_4 fichier de feuille en caculateur.kicad_sch.
Filtres d'empreinte R_Shunt_4 mis à jour en 'R_*'.
Connecter R_Shunt_4 pin 1 à GNDPWR.
Connecter R_Shunt_4 pin 2 à Net-(K2-Pad10).
Métadonnées de l'unité R_Shunt_4 mises à jour.
Modifie valeur C4 de C_0805_2012Metric_Pad1.18x1.45mm_HandSolder en 100nf.
Ajouté U1 (empreinte 'Converter_DCDC:Converter_DCDC_TRACO_TSR-1_THT').
Change la référence schématique de REF** en U1.
Modifie valeur U1 de Converter_DCDC_TRACO_TSR-1_THT en TSR_1-2433.
Mise à jour U1 association de symbole de  à /e76361c5-5503-4fd9-aaf5-17e6d84ac1f4.
Mise a Jour des Champs de U1.
Mis à jour U1 nom de feuille en /.
Mis à jour U1 fichier de feuille en caculateur.kicad_sch.
Filtres d'empreinte U1 mis à jour en 'Converter*DCDC*TRACO*TSR?1*'.
Connecter U1 pin 1 à Net-(U1-Vin).
Connecter U1 pin 2 à GND.
Connecter U1 pin 3 à Net-(U1-Vout).
Métadonnées de l'unité U1 mises à jour.
Mise à jour C4 association de symbole de  à /da7f24b8-9f54-4413-98a9-f3a4b3bf3647.
Ajouté U2 (empreinte 'Package_QFP:LQFP-64_10x10mm_P0.5mm').
Change la référence schématique de REF** en U2.
Modifie valeur U2 de LQFP-64_10x10mm_P0.5mm en STM32F103RBTx.
Mise à jour U2 association de symbole de  à /ed7a5284-8454-4959-9e88-a6edb71e836f.
Mise a Jour des Champs de U2.
Mis à jour U2 nom de feuille en /.
Mis à jour U2 fichier de feuille en caculateur.kicad_sch.
Filtres d'empreinte U2 mis à jour en 'LQFP*10x10mm*P0.5mm*'.
Ajout net Net-(U2-PC14).
Connecter U2 pin 3 à Net-(U2-PC14).
Ajout net unconnected-(U2-PD2-Pad54).
Connecter U2 pin 54 à unconnected-(U2-PD2-Pad54).
Ajout net Net-(U2-PB12).
Connecter U2 pin 33 à Net-(U2-PB12).
Connecter U2 pin 32 à Net-(U2-VBAT).
Ajout net unconnected-(U2-PB9-Pad62).
Connecter U2 pin 62 à unconnected-(U2-PB9-Pad62).
Ajout net Net-(U2-PA14).
Connecter U2 pin 49 à Net-(U2-PA14).
Ajout net unconnected-(U2-PA5-Pad21).
Connecter U2 pin 21 à unconnected-(U2-PA5-Pad21).
Ajout net Net-(U2-PC15).
Connecter U2 pin 4 à Net-(U2-PC15).
Ajout net Net-(U2-PA13).
Connecter U2 pin 46 à Net-(U2-PA13).
Connecter U2 pin 6 à Net-(U2-PD1).
Ajout net Net-(U2-PA9).
Connecter U2 pin 42 à Net-(U2-PA9).
Connecter U2 pin 1 à Net-(U2-VBAT).
Ajout net Net-(U2-PB13).
Connecter U2 pin 34 à Net-(U2-PB13).
Ajout net unconnected-(U2-PA6-Pad22).
Connecter U2 pin 22 à unconnected-(U2-PA6-Pad22).
Ajout net Net-(U2-PC1).
Connecter U2 pin 9 à Net-(U2-PC1).
Connecter U2 pin 12 à GND.
Ajout net unconnected-(U2-PA12-Pad45).
Connecter U2 pin 45 à unconnected-(U2-PA12-Pad45).
Connecter U2 pin 19 à Net-(U2-VBAT).
Ajout net Net-(U2-PA2).
Connecter U2 pin 16 à Net-(U2-PA2).
Ajout net Net-(U2-PC3).
Connecter U2 pin 11 à Net-(U2-PC3).
Ajout net Net-(U2-PB11).
Connecter U2 pin 30 à Net-(U2-PB11).
Ajout net Net-(U2-PA8).
Connecter U2 pin 41 à Net-(U2-PA8).
Ajout net Net-(U2-PC5).
Connecter U2 pin 25 à Net-(U2-PC5).
Ajout net Net-(U2-PC13).
Connecter U2 pin 2 à Net-(U2-PC13).
Ajout net Net-(U2-PC11).
Connecter U2 pin 52 à Net-(U2-PC11).
Ajout net Net-(U2-PA1).
Connecter U2 pin 15 à Net-(U2-PA1).
Ajout net Net-(U2-PA10).
Connecter U2 pin 43 à Net-(U2-PA10).
Ajout net Net-(U2-PB6).
Connecter U2 pin 58 à Net-(U2-PB6).
Ajout net Net-(U2-PB8).
Connecter U2 pin 61 à Net-(U2-PB8).
Ajout net Net-(U2-PB1).
Connecter U2 pin 27 à Net-(U2-PB1).
Connecter U2 pin 47 à GND.
Ajout net unconnected-(U2-PA4-Pad20).
Connecter U2 pin 20 à unconnected-(U2-PA4-Pad20).
Ajout net Net-(U2-PC9).
Connecter U2 pin 40 à Net-(U2-PC9).
Ajout net Net-(U2-PC12).
Connecter U2 pin 53 à Net-(U2-PC12).
Ajout net Net-(U2-PB5).
Connecter U2 pin 57 à Net-(U2-PB5).
Ajout net Net-(U2-PA3).
Connecter U2 pin 17 à Net-(U2-PA3).
Ajout net Net-(U2-PC0).
Connecter U2 pin 8 à Net-(U2-PC0).
Connecter U2 pin 64 à Net-(U2-VBAT).
Ajout net Net-(U2-PB0).
Connecter U2 pin 26 à Net-(U2-PB0).
Ajout net Net-(U2-PB4).
Connecter U2 pin 56 à Net-(U2-PB4).
Ajout net unconnected-(U2-PA11-Pad44).
Connecter U2 pin 44 à unconnected-(U2-PA11-Pad44).
Connecter U2 pin 48 à Net-(U2-VBAT).
Ajout net unconnected-(U2-PA7-Pad23).
Connecter U2 pin 23 à unconnected-(U2-PA7-Pad23).
Ajout net unconnected-(U2-PA15-Pad50).
Connecter U2 pin 50 à unconnected-(U2-PA15-Pad50).
Connecter U2 pin 7 à Net-(U2-NRST).
Ajout net Net-(U2-PC2).
Connecter U2 pin 10 à Net-(U2-PC2).
Connecter U2 pin 13 à Net-(U2-VBAT).
Ajout net Net-(U2-PB2).
Connecter U2 pin 28 à Net-(U2-PB2).
Ajout net Net-(U2-PC8).
Connecter U2 pin 39 à Net-(U2-PC8).
Ajout net Net-(U2-PC10).
Connecter U2 pin 51 à Net-(U2-PC10).
Connecter U2 pin 5 à Net-(U2-PD0).
Ajout net Net-(U2-PB3).
Connecter U2 pin 55 à Net-(U2-PB3).
Connecter U2 pin 31 à GND.
Ajout net unconnected-(U2-PB14-Pad35).
Connecter U2 pin 35 à unconnected-(U2-PB14-Pad35).
Ajout net Net-(U2-PB10).
Connecter U2 pin 29 à Net-(U2-PB10).
Ajout net Net-(U2-PB7).
Connecter U2 pin 59 à Net-(U2-PB7).
Ajout net Net-(U2-PC7).
Connecter U2 pin 38 à Net-(U2-PC7).
Ajout net Net-(U2-PC6).
Connecter U2 pin 37 à Net-(U2-PC6).
Connecter U2 pin 18 à GND.
Ajout net Net-(U2-PA0).
Connecter U2 pin 14 à Net-(U2-PA0).
Connecter U2 pin 60 à Net-(U2-BOOT0).
Connecter U2 pin 63 à GND.
Ajout net unconnected-(U2-PB15-Pad36).
Connecter U2 pin 36 à unconnected-(U2-PB15-Pad36).
Ajout net Net-(U2-PC4).
Connecter U2 pin 24 à Net-(U2-PC4).
Métadonnées de l'unité U2 mises à jour.
Mise a Jour des Champs de C4.
Ajouté U3 (empreinte 'Package_SO:SOIC-16_4.55x10.3mm_P1.27mm').
Change la référence schématique de REF** en U3.
Modifie valeur U3 de SOIC-16_4.55x10.3mm_P1.27mm en TLP291-4.
Mise à jour U3 association de symbole de  à /b1c514a0-f0fe-4b84-b60a-ca4d543d3c67.
Mise a Jour des Champs de U3.
Mis à jour U3 nom de feuille en /.
Mis à jour U3 fichier de feuille en caculateur.kicad_sch.
Filtres d'empreinte U3 mis à jour en 'SOIC*4.55x10.3mm*P1.27mm*'.
Connecter U3 pin 7 à Net-(R4-Pad2).
Ajout net Net-(U3-Pad6).
Connecter U3 pin 6 à Net-(U3-Pad6).
Connecter U3 pin 14 à Net-(R6-Pad1).
Connecter U3 pin 12 à Net-(R7-Pad1).
Connecter U3 pin 9 à GND.
Connecter U3 pin 13 à GND.
Connecter U3 pin 11 à GND.
Ajout net Net-(U3-Pad4).
Connecter U3 pin 4 à Net-(U3-Pad4).
Connecter U3 pin 5 à Net-(R3-Pad2).
Connecter U3 pin 1 à Net-(R1-Pad2).
Ajout net Net-(U3-Pad8).
Connecter U3 pin 8 à Net-(U3-Pad8).
Ajout net Net-(U3-Pad2).
Connecter U3 pin 2 à Net-(U3-Pad2).
Connecter U3 pin 3 à Net-(R2-Pad2).
Connecter U3 pin 16 à Net-(R5-Pad1).
Connecter U3 pin 15 à GND.
Connecter U3 pin 10 à Net-(R8-Pad1).
Métadonnées de l'unité U3 mises à jour.
Mis à jour C4 nom de feuille en /.
Ajouté U4 (empreinte 'Package_SO:SOIC-16_4.55x10.3mm_P1.27mm').
Change la référence schématique de REF** en U4.
Modifie valeur U4 de SOIC-16_4.55x10.3mm_P1.27mm en TLP291-4.
Mise à jour U4 association de symbole de  à /aef32dc1-29b5-48fd-a2ee-69e674da143c.
Mise a Jour des Champs de U4.
Mis à jour U4 nom de feuille en /.
Mis à jour U4 fichier de feuille en caculateur.kicad_sch.
Filtres d'empreinte U4 mis à jour en 'SOIC*4.55x10.3mm*P1.27mm*'.
Ajout net Net-(U4-Pad3).
Connecter U4 pin 3 à Net-(U4-Pad3).
Connecter U4 pin 11 à GND.
Connecter U4 pin 16 à Net-(R10-Pad1).
Connecter U4 pin 10 à Net-(R13-Pad1).
Connecter U4 pin 5 à Net-(R16-Pad2).
Ajout net Net-(U4-Pad8).
Connecter U4 pin 8 à Net-(U4-Pad8).
Connecter U4 pin 14 à Net-(R11-Pad1).
Connecter U4 pin 4 à Net-(R15-Pad2).
Connecter U4 pin 9 à GND.
Connecter U4 pin 15 à GND.
Connecter U4 pin 13 à GND.
Ajout net Net-(U4-Pad2).
Connecter U4 pin 2 à Net-(U4-Pad2).
Connecter U4 pin 1 à Net-(R14-Pad2).
Ajout net Net-(U4-Pad6).
Connecter U4 pin 6 à Net-(U4-Pad6).
Connecter U4 pin 7 à Net-(R17-Pad2).
Connecter U4 pin 12 à Net-(R12-Pad1).
Métadonnées de l'unité U4 mises à jour.
Mis à jour C4 fichier de feuille en caculateur.kicad_sch.
Ajouté U5 (empreinte 'Package_SO:SOIC-16_4.55x10.3mm_P1.27mm').
Change la référence schématique de REF** en U5.
Modifie valeur U5 de SOIC-16_4.55x10.3mm_P1.27mm en TLP291-4.
Mise à jour U5 association de symbole de  à /d36fa1c9-ec05-46ea-a350-de6e75563349.
Mise a Jour des Champs de U5.
Mis à jour U5 nom de feuille en /.
Mis à jour U5 fichier de feuille en caculateur.kicad_sch.
Filtres d'empreinte U5 mis à jour en 'SOIC*4.55x10.3mm*P1.27mm*'.
Ajout net Net-(U5-Pad6).
Connecter U5 pin 6 à Net-(U5-Pad6).
Ajout net Net-(U5-Pad2).
Connecter U5 pin 2 à Net-(U5-Pad2).
Connecter U5 pin 11 à GND.
Connecter U5 pin 1 à Net-(R18-Pad2).
Connecter U5 pin 13 à GND.
Connecter U5 pin 15 à GND.
Connecter U5 pin 16 à Net-(R22-Pad1).
Ajout net Net-(U5-Pad7).
Connecter U5 pin 7 à Net-(U5-Pad7).
Ajout net Net-(U5-Pad4).
Connecter U5 pin 4 à Net-(U5-Pad4).
Connecter U5 pin 3 à Net-(R19-Pad2).
Connecter U5 pin 14 à Net-(R23-Pad1).
Connecter U5 pin 9 à GND.
Connecter U5 pin 5 à Net-(R20-Pad2).
Connecter U5 pin 10 à Net-(R25-Pad1).
Connecter U5 pin 8 à Net-(R21-Pad2).
Connecter U5 pin 12 à Net-(R24-Pad1).
Métadonnées de l'unité U5 mises à jour.
Filtres d'empreinte C4 mis à jour en 'C_*'.
Ajouté U6 (empreinte 'Package_SO:SOIC-16_4.55x10.3mm_P1.27mm').
Change la référence schématique de REF** en U6.
Modifie valeur U6 de SOIC-16_4.55x10.3mm_P1.27mm en TLP291-4.
Mise à jour U6 association de symbole de  à /43702c20-f2c9-4ee2-ab45-112cbfb3e39f.
Mise a Jour des Champs de U6.
Mis à jour U6 nom de feuille en /.
Mis à jour U6 fichier de feuille en caculateur.kicad_sch.
Filtres d'empreinte U6 mis à jour en 'SOIC*4.55x10.3mm*P1.27mm*'.
Connecter U6 pin 10 à Net-(R35-Pad1).
Ajout net Net-(U6-Pad8).
Connecter U6 pin 8 à Net-(U6-Pad8).
Connecter U6 pin 13 à GND.
Connecter U6 pin 9 à GND.
Connecter U6 pin 1 à Net-(R28-Pad2).
Connecter U6 pin 11 à GND.
Ajout net Net-(U6-Pad4).
Connecter U6 pin 4 à Net-(U6-Pad4).
Connecter U6 pin 14 à Net-(R33-Pad1).
Connecter U6 pin 3 à Net-(R29-Pad2).
Ajout net Net-(U6-Pad6).
Connecter U6 pin 6 à Net-(U6-Pad6).
Connecter U6 pin 16 à Net-(R32-Pad1).
Connecter U6 pin 15 à GND.
Connecter U6 pin 7 à Net-(R31-Pad2).
Ajout net Net-(U6-Pad2).
Connecter U6 pin 2 à Net-(U6-Pad2).
Connecter U6 pin 12 à Net-(R34-Pad1).
Connecter U6 pin 5 à Net-(R30-Pad2).
Métadonnées de l'unité U6 mises à jour.
Connecter C4 pin 2 à GND.
Ajouté U7 (empreinte 'Package_SO:Infineon_SOIC-20W_7.6x12.8mm_P1.27mm').
Change la référence schématique de REF** en U7.
Modifie valeur U7 de Infineon_SOIC-20W_7.6x12.8mm_P1.27mm en BTS711L1.
Mise à jour U7 association de symbole de  à /7b65a6af-9f43-4bfd-9449-96a01d43a77e.
Mise a Jour des Champs de U7.
Mis à jour U7 nom de feuille en /.
Mis à jour U7 fichier de feuille en caculateur.kicad_sch.
Filtres d'empreinte U7 mis à jour en '*SO*7.6*12.*P1.27mm*'.
Ajout net unconnected-(U7-OUT4-Pad13).
Connecter U7 pin 13 à unconnected-(U7-OUT4-Pad13).
Connecter U7 pin 1 à VBB.
Ajout net unconnected-(U7-ST3/4-Pad8).
Connecter U7 pin 8 à unconnected-(U7-ST3/4-Pad8).
Connecter U7 pin 15 à VBB.
Connecter U7 pin 3 à Net-(U7-IN1).
Connecter U7 pin 10 à VBB.
Ajout net Net-(U7-OUT1).
Connecter U7 pin 18 à Net-(U7-OUT1).
Connecter U7 pin 16 à VBB.
Connecter U7 pin 2 à Net-(D6-A).
Ajout net Net-(U7-OUT3).
Connecter U7 pin 14 à Net-(U7-OUT3).
Ajout net unconnected-(U7-IN4-Pad9).
Connecter U7 pin 9 à unconnected-(U7-IN4-Pad9).
Connecter U7 pin 6 à Net-(D7-A).
Ajout net Net-(U7-OUT2).
Connecter U7 pin 17 à Net-(U7-OUT2).
Connecter U7 pin 5 à Net-(U7-IN2).
Connecter U7 pin 7 à Net-(U7-IN3).
Connecter U7 pin 12 à VBB.
Ajout net unconnected-(U7-ST1/2-Pad4).
Connecter U7 pin 4 à unconnected-(U7-ST1/2-Pad4).
Connecter U7 pin 11 à VBB.
Connecter U7 pin 19 à VBB.
Connecter U7 pin 20 à VBB.
Métadonnées de l'unité U7 mises à jour.
Connecter C4 pin 1 à Net-(U1-Vout).
Ajouté U9 (empreinte 'Package_SO:SOIC-8_3.9x4.9mm_P1.27mm').
Change la référence schématique de REF** en U9.
Modifie valeur U9 de SOIC-8_3.9x4.9mm_P1.27mm en LM2904.
Mise à jour U9 association de symbole de  à /b4f2820f-53b7-41e1-a1c6-1e64c276f34b.
Mise a Jour des Champs de U9.
Mis à jour U9 nom de feuille en /.
Mis à jour U9 fichier de feuille en caculateur.kicad_sch.
Filtres d'empreinte U9 mis à jour en 'SOIC*3.9x4.9mm*P1.27mm* DIP*W7.62mm* TO*99* OnSemi*Micro8* TSSOP*3x3mm*P0.65mm* TSSOP*4.4x3mm*P0.65mm* MSOP*3x3mm*P0.65mm* SSOP*3.9x4.9mm*P0.635mm* LFCSP*2x2mm*P0.5mm* *SIP* SOIC*5.3x6.2mm*P1.27mm*'.
Connecter U9 pin 6 à Net-(U9B--).
Ajout net Net-(U9C-V+).
Connecter U9 pin 8 à Net-(U9C-V+).
Connecter U9 pin 3 à Net-(U9A-+).
Connecter U9 pin 7 à Net-(R54-Pad1).
Connecter U9 pin 2 à Net-(U9A--).
Connecter U9 pin 1 à Net-(R49-Pad1).
Connecter U9 pin 5 à Net-(U9B-+).
Connecter U9 pin 4 à GND.
Métadonnées de l'unité U9 mises à jour.
Métadonnées de l'unité C4 mises à jour.
Ajouté U10 (empreinte 'RF_Module:Microchip_RN4871').
Change la référence schématique de REF** en U10.
Modifie valeur U10 de Microchip_RN4871 en RN4871.
Mise à jour U10 association de symbole de  à /114b87d5-c0c5-49bd-8a99-aa3578a064ee.
Mise a Jour des Champs de U10.
Mis à jour U10 nom de feuille en /.
Mis à jour U10 fichier de feuille en caculateur.kicad_sch.
Filtres d'empreinte U10 mis à jour en 'RF*Module:Microchip*RN4871*'.
Connecter U10 pin 14 à Net-(U10-VBAT).
Connecter U10 pin 2 à GND.
Ajout net unconnected-(U10-P2_0-Pad16).
Connecter U10 pin 16 à unconnected-(U10-P2_0-Pad16).
Ajout net Net-(U10-UART_TX).
Connecter U10 pin 8 à Net-(U10-UART_TX).
Ajout net unconnected-(U10-P1_7-Pad5).
Connecter U10 pin 5 à unconnected-(U10-P1_7-Pad5).
Ajout net unconnected-(U10-P2_7-Pad15).
Connecter U10 pin 15 à unconnected-(U10-P2_7-Pad15).
Ajout net Net-(U10-UART_RX).
Connecter U10 pin 7 à Net-(U10-UART_RX).
Ajout net unconnected-(U10-P1_3-Pad4).
Connecter U10 pin 4 à unconnected-(U10-P1_3-Pad4).
Ajout net unconnected-(U10-P0_0-Pad11).
Connecter U10 pin 11 à unconnected-(U10-P0_0-Pad11).
Ajout net unconnected-(U10-P3_6-Pad9).
Connecter U10 pin 9 à unconnected-(U10-P3_6-Pad9).
Ajout net unconnected-(U10-P1_6-Pad6).
Connecter U10 pin 6 à unconnected-(U10-P1_6-Pad6).
Connecter U10 pin 13 à GND.
Ajout net Net-(U10-RST).
Connecter U10 pin 10 à Net-(U10-RST).
Ajout net unconnected-(U10-BT_RF-Pad1).
Connecter U10 pin 1 à unconnected-(U10-BT_RF-Pad1).
Ajout net unconnected-(U10-P0_2-Pad12).
Connecter U10 pin 12 à unconnected-(U10-P0_2-Pad12).
Ajout net unconnected-(U10-P1_2-Pad3).
Connecter U10 pin 3 à unconnected-(U10-P1_2-Pad3).
Métadonnées de l'unité U10 mises à jour.
Ajouté C5 (empreinte 'Capacitor_SMD:C_0805_2012Metric_Pad1.18x1.45mm_HandSolder').
Ajouté U11 (empreinte 'Package_DIP:DIP-18_W7.62mm').
Change la référence schématique de REF** en U11.
Modifie valeur U11 de DIP-18_W7.62mm en ULN2803A.
Mise à jour U11 association de symbole de  à /323c0d1b-6a89-4e3d-852b-0fa0b9cdfc7b.
Mise a Jour des Champs de U11.
Mis à jour U11 nom de feuille en /.
Mis à jour U11 fichier de feuille en caculateur.kicad_sch.
Filtres d'empreinte U11 mis à jour en 'DIP*W7.62mm* SOIC*7.5x11.6mm*P1.27mm*'.
Connecter U11 pin 9 à GND.
Connecter U11 pin 11 à Net-(U11-O8).
Ajout net Net-(U11-I5).
Connecter U11 pin 5 à Net-(U11-I5).
Connecter U11 pin 12 à Net-(U11-O7).
Ajout net Net-(U11-I2).
Connecter U11 pin 2 à Net-(U11-I2).
Ajout net Net-(U11-O1).
Connecter U11 pin 18 à Net-(U11-O1).
Ajout net Net-(U11-O3).
Connecter U11 pin 16 à Net-(U11-O3).
Ajout net Net-(U11-I7).
Connecter U11 pin 7 à Net-(U11-I7).
Ajout net Net-(U11-I4).
Connecter U11 pin 4 à Net-(U11-I4).
Ajout net Net-(U11-I1).
Connecter U11 pin 1 à Net-(U11-I1).
Ajout net Net-(U11-I6).
Connecter U11 pin 6 à Net-(U11-I6).
Ajout net Net-(U11-O4).
Connecter U11 pin 15 à Net-(U11-O4).
Ajout net Net-(U11-O6).
Connecter U11 pin 13 à Net-(U11-O6).
Ajout net Net-(U11-I8).
Connecter U11 pin 8 à Net-(U11-I8).
Ajout net Net-(U11-O5).
Connecter U11 pin 14 à Net-(U11-O5).
Ajout net Net-(U11-O2).
Connecter U11 pin 17 à Net-(U11-O2).
Ajout net Net-(U11-I3).
Connecter U11 pin 3 à Net-(U11-I3).
Ajout net Net-(U11-COM).
Connecter U11 pin 10 à Net-(U11-COM).
Métadonnées de l'unité U11 mises à jour.
Change la référence schématique de REF** en C5.
Ajouté Y1 (empreinte 'Crystal:Crystal_SMD_5032-4Pin_5.0x3.2mm').
Change la référence schématique de REF** en Y1.
Modifie valeur Y1 de Crystal_SMD_5032-4Pin_5.0x3.2mm en Crystal_GND24_Small.
Mise à jour Y1 association de symbole de  à /2ac28d3e-35d5-431c-b066-f1a3f4d0fde4.
Mise a Jour des Champs de Y1.
Mis à jour Y1 nom de feuille en /.
Mis à jour Y1 fichier de feuille en caculateur.kicad_sch.
Filtres d'empreinte Y1 mis à jour en 'Crystal*'.
Connecter Y1 pin 1 à Net-(U2-PD0).
Connecter Y1 pin 3 à Net-(U2-PD1).
Connecter Y1 pin 2 à GND.
Connecter Y1 pin 4 à GND.
Métadonnées de l'unité Y1 mises à jour.

Info: Total warnings: 0, erreurs: 0.

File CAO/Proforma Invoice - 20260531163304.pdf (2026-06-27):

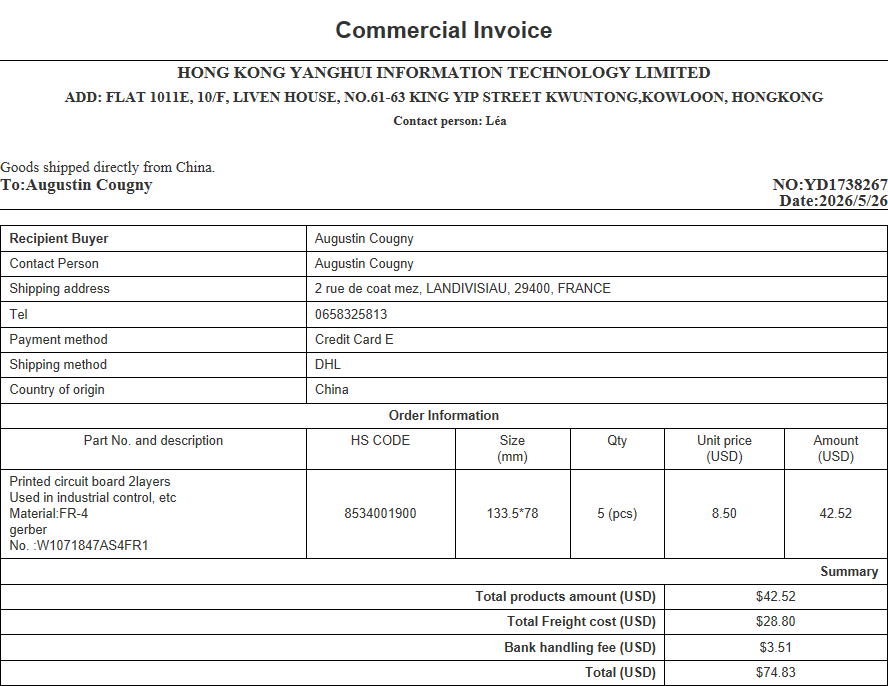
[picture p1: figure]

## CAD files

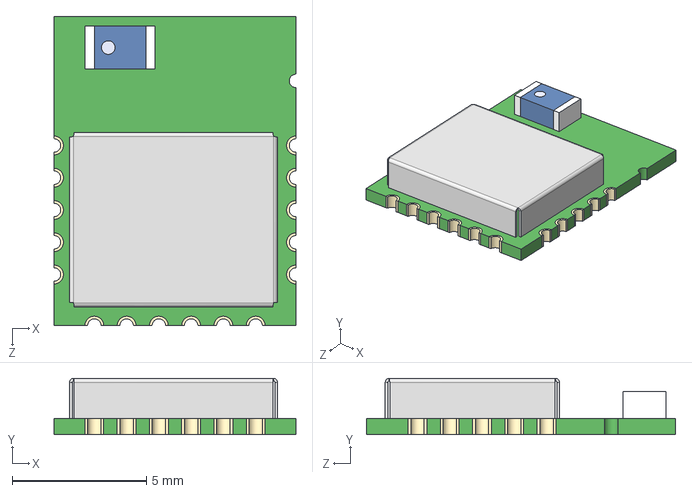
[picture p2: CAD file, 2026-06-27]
CAO/empreinte/RN4871-V_RM118.STEP
9.00 x 2.10 x 11.5 mm

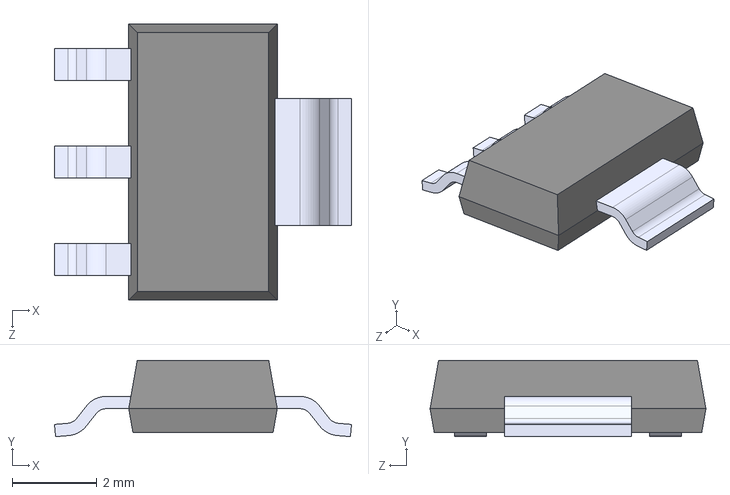
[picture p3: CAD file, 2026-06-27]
CAO/empreinte/LM2936MP-3.3.step
7.00 x 1.80 x 6.50 mm

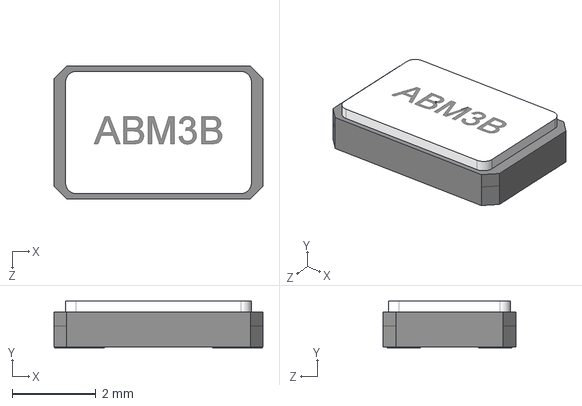
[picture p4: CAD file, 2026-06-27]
CAO/empreinte/ABM3B-8.000MHZ-10-1UT--3DModel-STEP-400430.STEP
5.00 x 1.11 x 3.18 mm

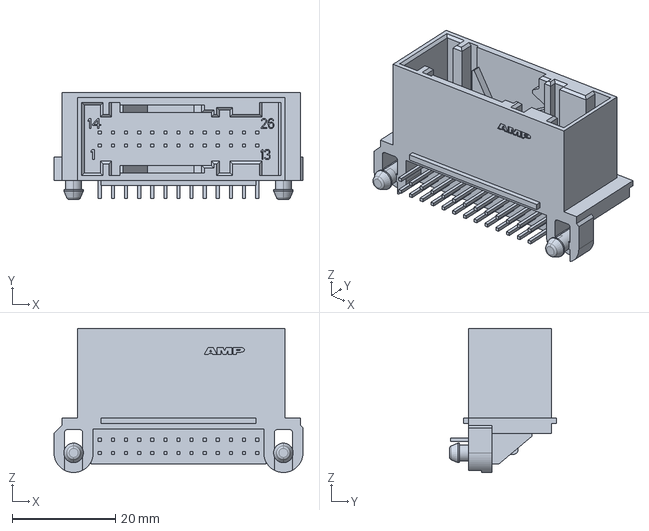
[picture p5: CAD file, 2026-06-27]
CAO/empreinte/185534-3--3DModel-STEP-1.STEP
48.2 x 20.7 x 27.9 mm

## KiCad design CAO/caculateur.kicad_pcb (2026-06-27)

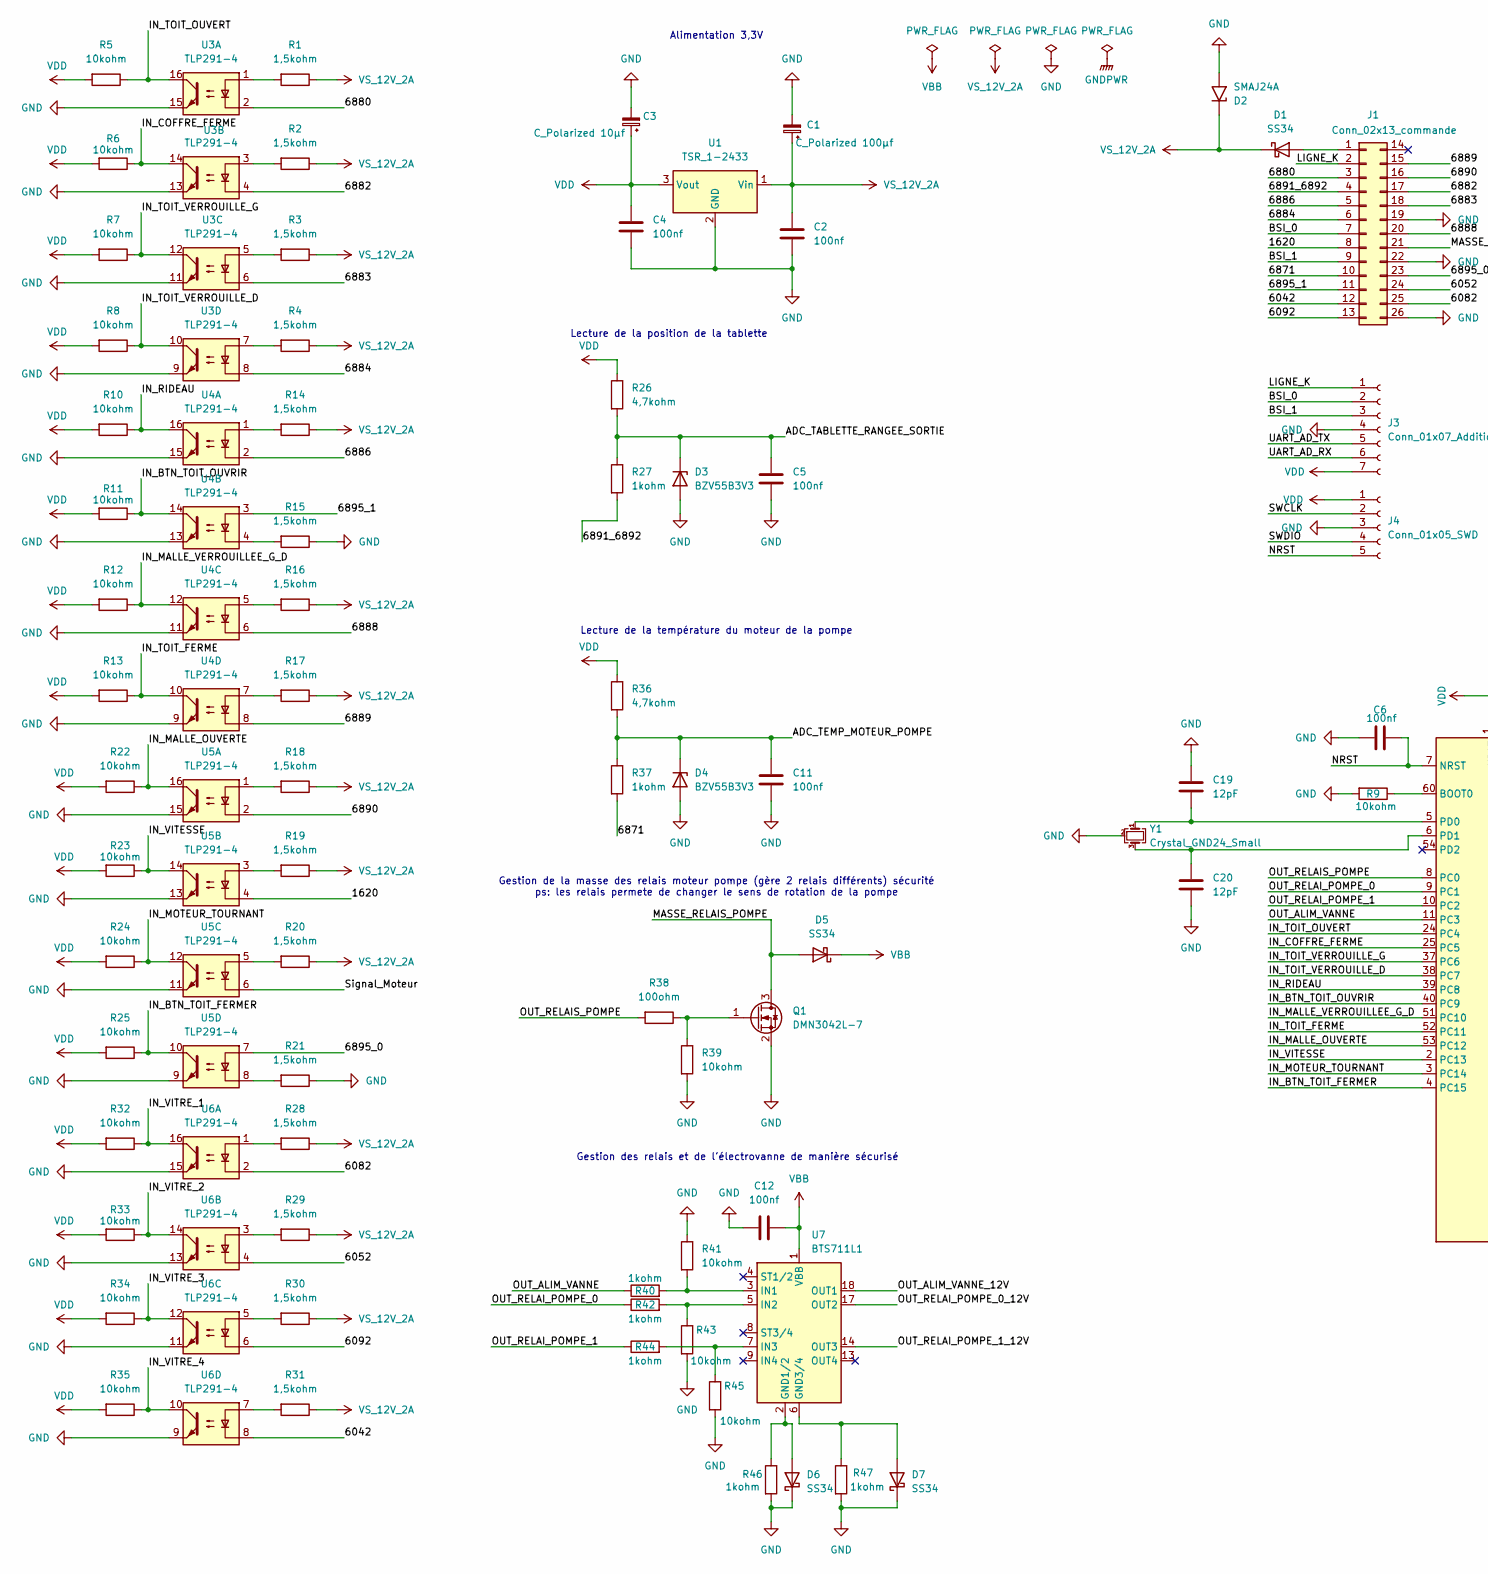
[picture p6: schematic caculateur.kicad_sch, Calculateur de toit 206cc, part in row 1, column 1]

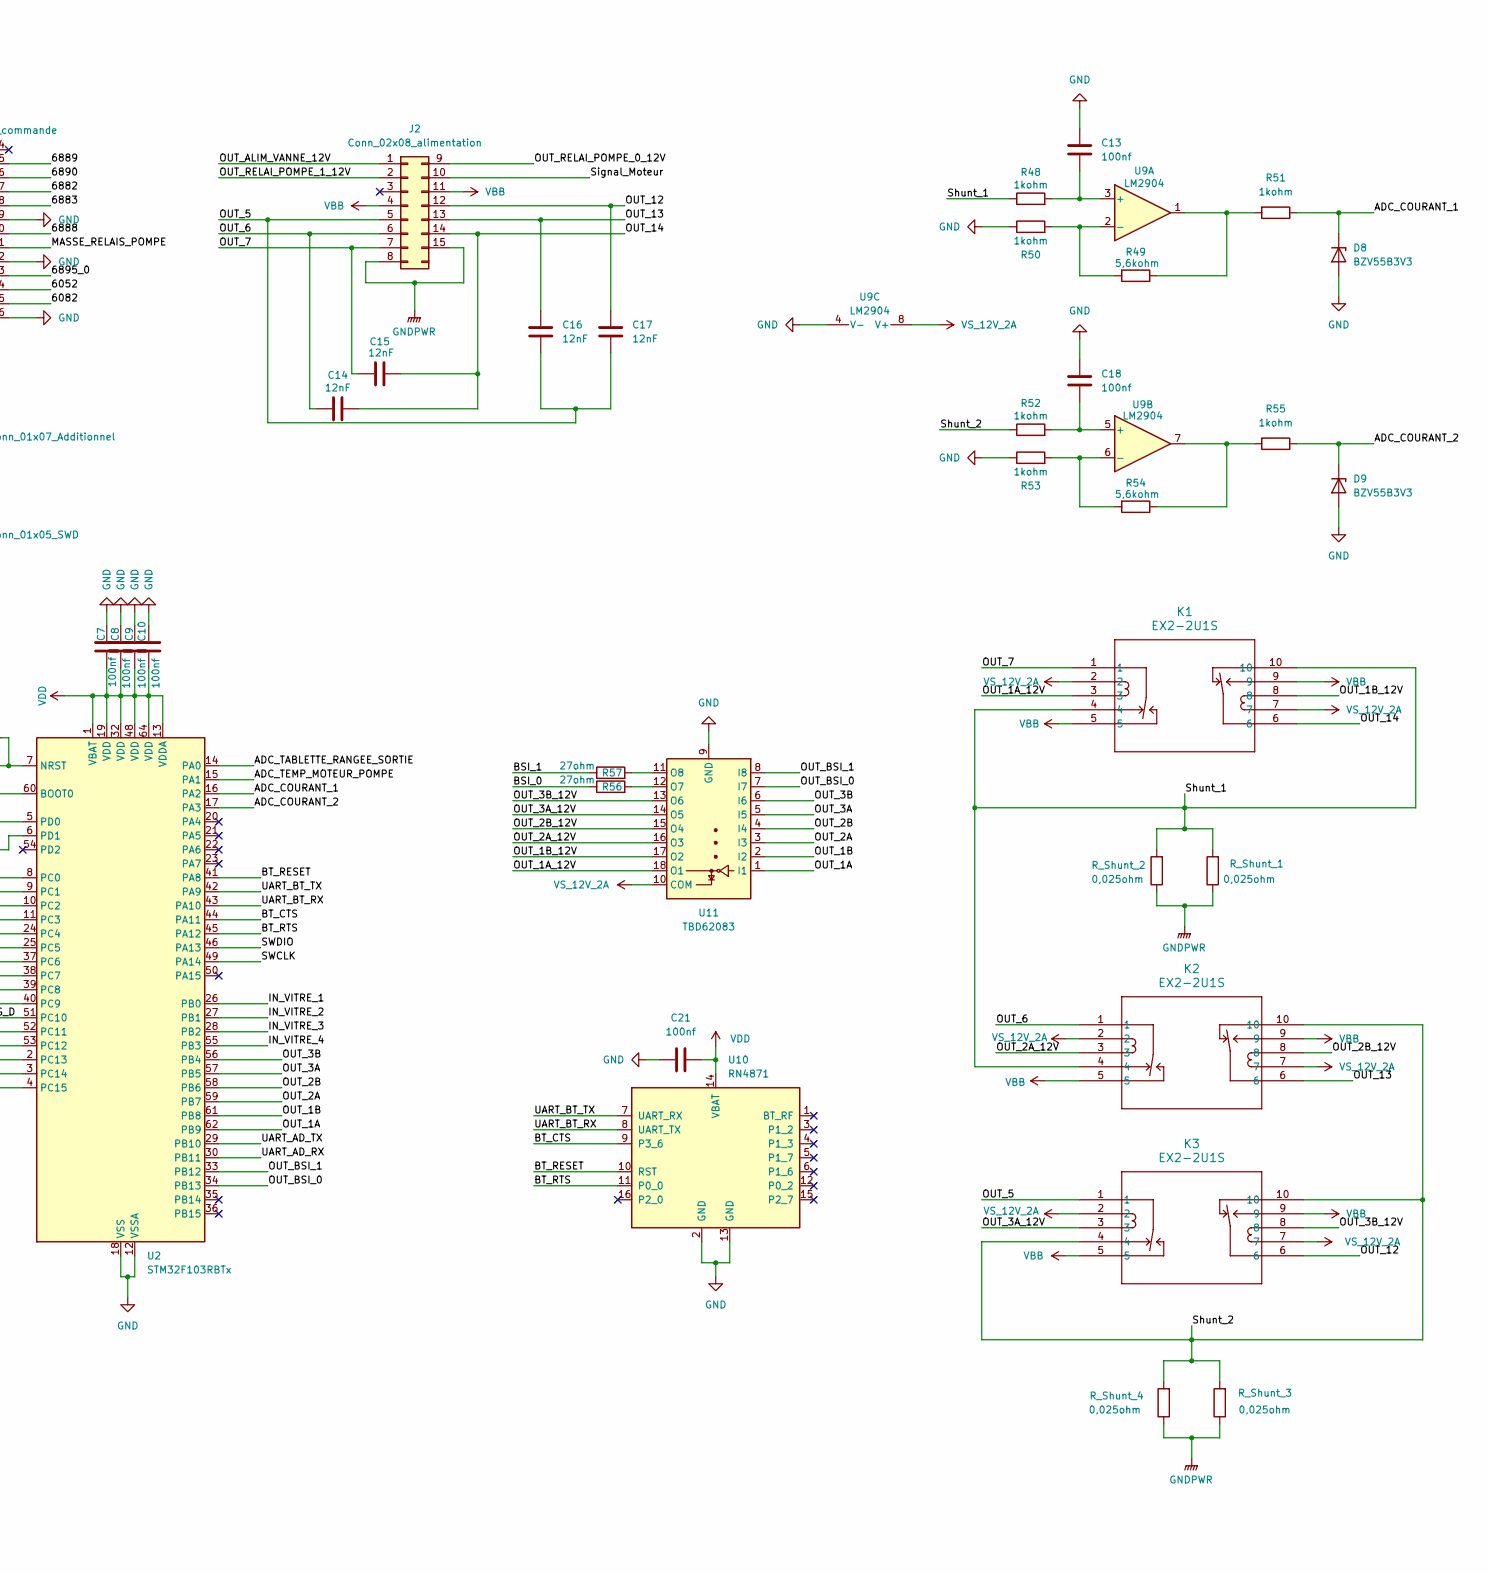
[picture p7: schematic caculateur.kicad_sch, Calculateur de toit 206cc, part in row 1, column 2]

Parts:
C1: C_Polarized 100µf; CP_Elec_10x10
C2, C4, C5, C6, C7, C8, C9, C10, C11, C12, C13, C18, C21: 100nf; C_0805_2012Metric_Pad1.18x1.45mm_HandSolder
C3: C_Polarized 10µf; CP_EIA-3216-18_Kemet-A_HandSolder
C14, C15, C16, C17: 12nF; C_1206_3216Metric
C19, C20: 12pF; C_0805_2012Metric_Pad1.18x1.45mm_HandSolder
D1, D5, D6, D7: SS34; D_SMA
D2: SMAJ24A; D_SMA
D3, D4, D8, D9: BZV55B3V3; D_MiniMELF
J1: Conn_02x13_commande; Connecteur_Jaune_206CC_26P
J2: Conn_02x08_alimentation; Connecteur_Jaune_206CC_15P
J3: Conn_01x07_Additionnel; Hirose_FH12-8S-0.5SH_1x08-1MP_P0.50mm_Horizontal
J4: Conn_01x05_SWD; Tag-Connect_TC2030-IDC-NL_2x03_P1.27mm_Vertical
K1, K2, K3: EX2-2U1S; EX2_NEC
Q1: DMN3042L-7; SOT-23
R1, R2, R3, R4, R14, R15, R16, R17, R18, R19, R20, R21, R28, R29, R30, R31: 1,5kohm; R_0805_2012Metric_Pad1.20x1.40mm_HandSolder
R5, R6, R7, R8, R9, R10, R11, R12, R13, R22, R23, R24, R25, R32, R33, R34, R35, R39, R41, R43, R45: 10kohm; R_0805_2012Metric_Pad1.20x1.40mm_HandSolder
R26, R36: 4,7kohm; R_0805_2012Metric_Pad1.20x1.40mm_HandSolder
R27, R37: 1kohm; R_1206_3216Metric
R38: 100ohm; R_0805_2012Metric_Pad1.20x1.40mm_HandSolder
R40, R42, R44, R46, R47, R48, R50, R51, R52, R53, R55: 1kohm; R_0805_2012Metric_Pad1.20x1.40mm_HandSolder
R49, R54: 5,6kohm; R_0805_2012Metric_Pad1.20x1.40mm_HandSolder
R56, R57: 27ohm; R_1206_3216Metric
R_Shunt_1, R_Shunt_2, R_Shunt_3, R_Shunt_4: 0,025ohm; R_Shunt_Vishay_WSR2_WSR3
U1: TSR_1-2433; Converter_DCDC_TRACO_TSR-1_THT
U2: STM32F103RBTx; LQFP-64_10x10mm_P0.5mm
U3, U4, U5, U6: TLP291-4; SOIC-16_4.55x10.3mm_P1.27mm
U7: BTS711L1; Infineon_SOIC-20W_7.6x12.8mm_P1.27mm
U9: LM2904; SOIC-8_3.9x4.9mm_P1.27mm
U10: RN4871; Microchip_RN4871
U11: TBD62083; SSOP-18_4.4x6.5mm_P0.65mm
Y1: Crystal_GND24_Small; Crystal_SMD_5032-4Pin_5.0x3.2mm

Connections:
/1620: J1.8, U5.4
/6042: J1.12, U6.8
/6052: J1.24, U6.4
/6082: J1.25, U6.2
/6092: J1.13, U6.6
/6871: J1.10, R37.2
/6880: J1.3, U3.2
/6882: J1.17, U3.4
/6883: J1.18, U3.6
/6884: J1.6, U3.8
/6886: J1.5, U4.2
/6888: J1.20, U4.6
/6889: J1.15, U4.8
/6890: J1.16, U5.2
/6891_6892: J1.4, R27.2
/6895_0: J1.23, U5.7
/6895_1: J1.11, U4.3
/ADC_COURANT_1: D8.1 (K), R51.1, U2.16 (PA2)
/ADC_COURANT_2: D9.1 (K), R55.1, U2.17 (PA3)
/ADC_TABLETTE_RANGEE_SORTIE: C5.1, D3.1 (K), R26.2, R27.1, U2.14 (PA0)
/ADC_TEMP_MOTEUR_POMPE: C11.1, D4.1 (K), R36.2, R37.1, U2.15 (PA1)
/BSI_0: J1.7, J3.2, R56.1
/BSI_1: J1.9, J3.3, R57.1
/BT_CTS: U2.44 (PA11), U10.9 (P3_6)
/BT_RESET: U2.41 (PA8), U10.10 (RST)
/BT_RTS: U2.45 (PA12), U10.11 (P0_0)
/IN_BTN_TOIT_FERMER: R25.1, U2.4 (PC15), U5.10
/IN_BTN_TOIT_OUVRIR: R11.1, U2.40 (PC9), U4.14
/IN_COFFRE_FERME: R6.1, U2.25 (PC5), U3.14
/IN_MALLE_OUVERTE: R22.1, U2.53 (PC12), U5.16
/IN_MALLE_VERROUILLEE_G_D: R12.1, U2.51 (PC10), U4.12
/IN_MOTEUR_TOURNANT: R24.1, U2.3 (PC14), U5.12
/IN_RIDEAU: R10.1, U2.39 (PC8), U4.16
/IN_TOIT_FERME: R13.1, U2.52 (PC11), U4.10
/IN_TOIT_OUVERT: R5.1, U2.24 (PC4), U3.16
/IN_TOIT_VERROUILLE_D: R8.1, U2.38 (PC7), U3.10
/IN_TOIT_VERROUILLE_G: R7.1, U2.37 (PC6), U3.12
/IN_VITESSE: R23.1, U2.2 (PC13), U5.14
/IN_VITRE_1: R32.1, U2.26 (PB0), U6.16
/IN_VITRE_2: R33.1, U2.27 (PB1), U6.14
/IN_VITRE_3: R34.1, U2.28 (PB2), U6.12
/IN_VITRE_4: R35.1, U2.55 (PB3), U6.10
/LIGNE_K: J1.2, J3.1
/MASSE_RELAIS_POMPE: D5.2 (A), J1.21, Q1.3 (D)
/NRST: C6.1, J4.5, U2.7 (NRST)
/OUT_1A: U2.62 (PB9), U11.1 (I1)
/OUT_1A_12V: K1.3, U11.18 (O1)
/OUT_1B: U2.61 (PB8), U11.2 (I2)
/OUT_1B_12V: K1.8, U11.17 (O2)
/OUT_2A: U2.59 (PB7), U11.3 (I3)
/OUT_2A_12V: K2.3, U11.16 (O3)
/OUT_2B: U2.58 (PB6), U11.4 (I4)
/OUT_2B_12V: K2.8, U11.15 (O4)
/OUT_3A: U2.57 (PB5), U11.5 (I5)
/OUT_3A_12V: K3.3, U11.14 (O5)
/OUT_3B: U2.56 (PB4), U11.6 (I6)
/OUT_3B_12V: K3.8, U11.13 (O6)
/OUT_5: C16.2, C17.2, J2.5, K3.1
/OUT_6: C14.2, J2.6, K2.1
/OUT_7: C15.2, J2.7, K1.1
/OUT_12: C17.1, J2.12, K3.6
/OUT_13: C16.1, J2.13, K2.6
/OUT_14: C14.1, C15.1, J2.14, K1.6
/OUT_ALIM_VANNE: R40.1, U2.11 (PC3)
/OUT_ALIM_VANNE_12V: J2.1, U7.18 (OUT1)
/OUT_BSI_0: U2.34 (PB13), U11.7 (I7)
/OUT_BSI_1: U2.33 (PB12), U11.8 (I8)
/OUT_RELAIS_POMPE: R38.2, U2.8 (PC0)
/OUT_RELAI_POMPE_0: R42.1, U2.9 (PC1)
/OUT_RELAI_POMPE_0_12V: J2.9, U7.17 (OUT2)
/OUT_RELAI_POMPE_1: R44.1, U2.10 (PC2)
/OUT_RELAI_POMPE_1_12V: J2.2, U7.14 (OUT3)
/SWCLK: J4.2, U2.49 (PA14)
/SWDIO: J4.4, U2.46 (PA13)
/Shunt_1: K1.4, K1.10, K2.4, R48.1, R_Shunt_1.2, R_Shunt_2.2
/Shunt_2: K2.10, K3.4, K3.10, R52.1, R_Shunt_3.2, R_Shunt_4.2
/Signal_Moteur: J2.10, U5.6
/UART_AD_RX: J3.6, U2.30 (PB11)
/UART_AD_TX: J3.5, U2.29 (PB10)
/UART_BT_RX: U2.43 (PA10), U10.8 (UART_TX)
/UART_BT_TX: U2.42 (PA9), U10.7 (UART_RX)
GND: C1.2, C2.2, C3.2, C4.2, C5.2, C6.2, C7.2, C8.2, C9.2, C10.2, C11.2, C12.2, C13.1, C18.1, C19.1, C20.2, C21.2, D2.2 (A2), D3.2 (A), D4.2 (A), D6.1 (K), D7.1 (K), D8.2 (A), D9.2 (A), J1.19, J1.22, J1.26, J3.4, J4.3, Q1.2 (S), R9.2, R15.1, R21.1, R39.2, R41.1, R43.2, R45.2, R46.2, R47.2, R50.1, R53.1, U1.2 (GND), U2.12 (VSSA), U2.18 (VSS), U2.31 (VSS), U2.47 (VSS), U2.63 (VSS), U3.9, U3.11, U3.13, U3.15, U4.9, U4.11, U4.13, U4.15, U5.9, U5.11, U5.13, U5.15, U6.9, U6.11, U6.13, U6.15, U9.4 (V-), U10.2 (GND), U10.13 (GND), U11.9 (GND), Y1.2 (G), Y1.4 (G)
GNDPWR: J2.8, J2.15, R_Shunt_1.1, R_Shunt_2.1, R_Shunt_3.1, R_Shunt_4.1
unnamed: D1.2 (A), J1.1
unnamed: D6.2 (A), R46.1, U7.2 (GND1/2)
unnamed: D7.2 (A), R47.1, U7.6 (GND3/4)
unnamed: Q1.1 (G), R38.1, R39.1
unnamed: R1.2, U3.1
unnamed: R2.2, U3.3
unnamed: R3.2, U3.5
unnamed: R4.2, U3.7
unnamed: R14.2, U4.1
unnamed: R15.2, U4.4
unnamed: R16.2, U4.5
unnamed: R17.2, U4.7
unnamed: R18.2, U5.1
unnamed: R19.2, U5.3
unnamed: R20.2, U5.5
unnamed: R21.2, U5.8
unnamed: R28.2, U6.1
unnamed: R29.2, U6.3
unnamed: R30.2, U6.5
unnamed: R31.2, U6.7
unnamed: R49.1, R51.2, U9.1
unnamed: R54.1, R55.2, U9.7
unnamed: R9.1, U2.60 (BOOT0)
unnamed: C19.2, U2.5 (PD0), Y1.1
unnamed: C20.1, U2.6 (PD1), Y1.3
unnamed: R40.2, R41.2, U7.3 (IN1)
unnamed: R42.2, R43.1, U7.5 (IN2)
unnamed: R44.2, R45.1, U7.7 (IN3)
unnamed: C13.2, R48.2, U9.3 (+)
unnamed: R49.2, R50.2, U9.2 (-)
unnamed: C18.2, R52.2, U9.5 (+)
unnamed: R53.2, R54.2, U9.6 (-)
unnamed: R56.2, U11.12 (O7)
unnamed: R57.2, U11.11 (O8)

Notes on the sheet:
Gestion de la masse des relais moteur pompe (gère 2 relais différents) sécurité ps: les relais permete de changer le sens de rotation de la pompe
Lecture de la température du moteur de la pompe
Alimentation 3,3V
Gestion des relais et de l'électrovanne de manière sécurisé
Lecture de la position de la tablette

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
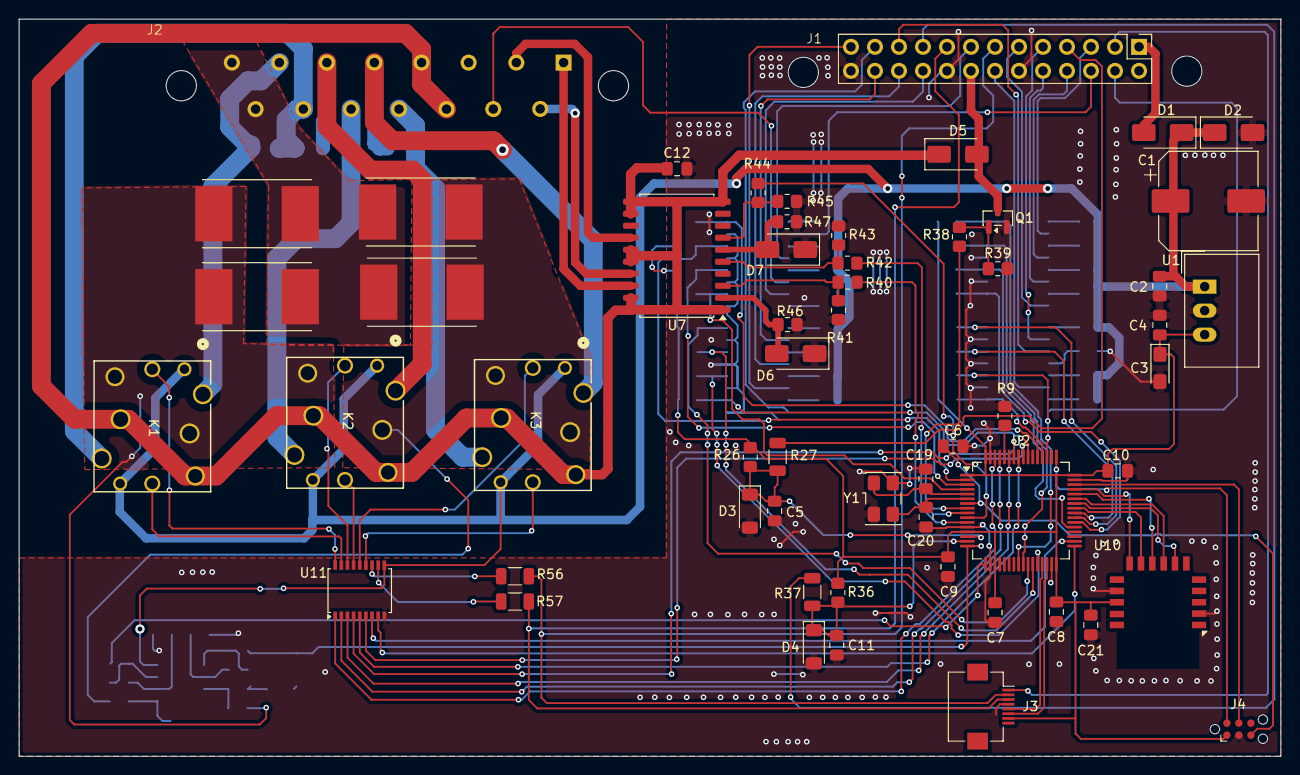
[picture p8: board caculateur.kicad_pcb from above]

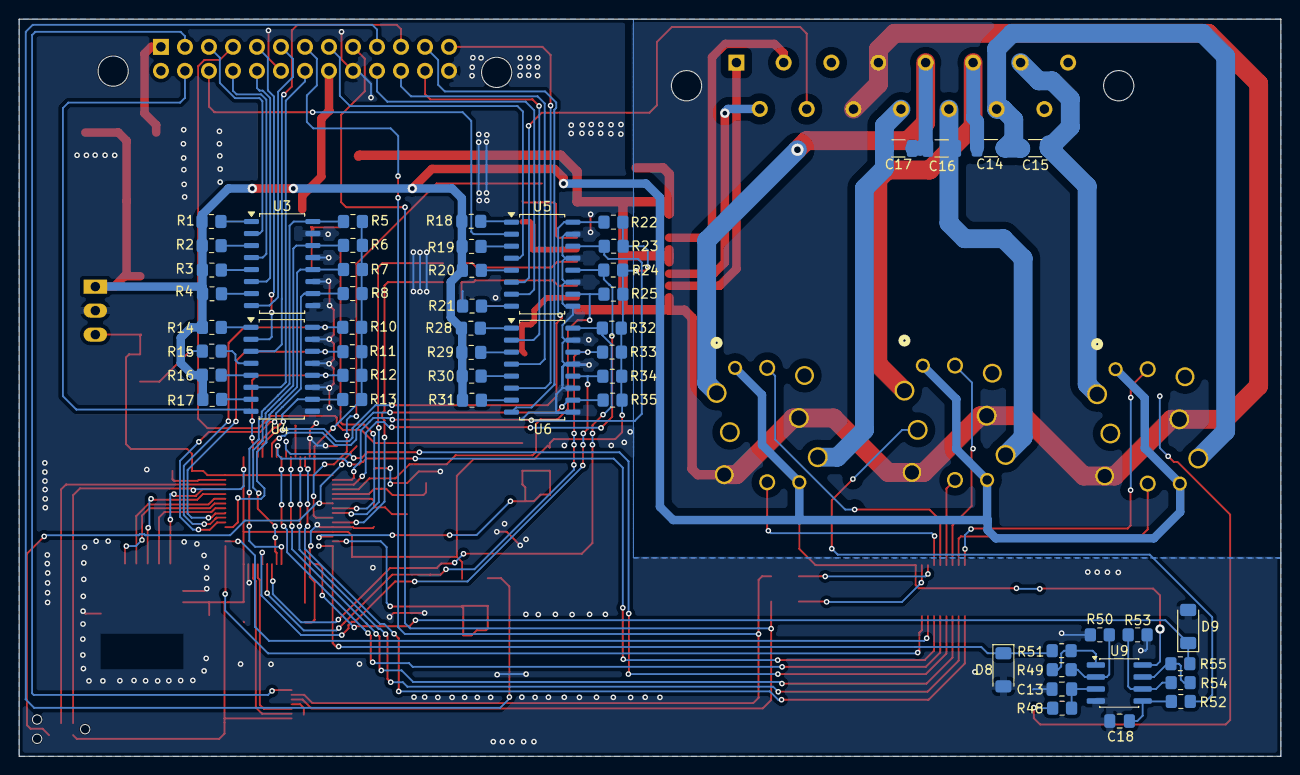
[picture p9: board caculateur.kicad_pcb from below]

Board: 2 copper layers, 133.5 x 78.0 mm, 110 parts (53 on the bottom side), 120 nets.

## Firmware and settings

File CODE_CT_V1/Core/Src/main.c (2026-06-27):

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
/* Includes ------------------------------------------------------------------*/
#include "main.h"
#include "cmsis_os.h"

/* USER CODE BEGIN Includes */
#include "vitres.h"
/* USER CODE END Includes */

ADC_HandleTypeDef hadc1;
DMA_HandleTypeDef hdma_adc1;

UART_HandleTypeDef huart1;
UART_HandleTypeDef huart3;

/* Definitions for TaskToit */
osThreadId_t TaskToitHandle;
const osThreadAttr_t TaskToit_attributes = {
  .name = "TaskToit",
  .stack_size = 256 * 4,
  .priority = (osPriority_t) osPriorityHigh,
};
/* Definitions for TaskBle */
osThreadId_t TaskBleHandle;
const osThreadAttr_t TaskBle_attributes = {
  .name = "TaskBle",
  .stack_size = 512 * 4,
  .priority = (osPriority_t) osPriorityNormal,
};
/* Definitions for TaskDiag */
osThreadId_t TaskDiagHandle;
const osThreadAttr_t TaskDiag_attributes = {
  .name = "TaskDiag",
  .stack_size = 128 * 4,
  .priority = (osPriority_t) osPriorityLow,
};
void SystemClock_Config(void);
static void MX_GPIO_Init(void);
static void MX_DMA_Init(void);
static void MX_USART1_UART_Init(void);
static void MX_USART3_UART_Init(void);
static void MX_ADC1_Init(void);
void StartTaskToit(void *argument);
void StartTaskBle(void *argument);
void StartTaskDiag(void *argument);

/**
  * @brief  The application entry point.
  * @retval int
  */
int main(void)
{

  /* MCU Configuration--------------------------------------------------------*/

  /* Reset of all peripherals, Initializes the Flash interface and the Systick. */
  HAL_Init();

  /* Configure the system clock */
  SystemClock_Config();

  /* Initialize all configured peripherals */
  MX_GPIO_Init();
  MX_DMA_Init();
  MX_USART1_UART_Init();
  MX_USART3_UART_Init();
  MX_ADC1_Init();
  /* Init scheduler */
  osKernelInitialize();

  /* USER CODE BEGIN RTOS_MUTEX */
  /* add mutexes, ... */
  /* USER CODE END RTOS_MUTEX */

  /* USER CODE BEGIN RTOS_SEMAPHORES */
  /* add semaphores, ... */
  /* USER CODE END RTOS_SEMAPHORES */

  /* USER CODE BEGIN RTOS_TIMERS */
  /* start timers, add new ones, ... */
  /* USER CODE END RTOS_TIMERS */

  /* USER CODE BEGIN RTOS_QUEUES */
  /* add queues, ... */
  /* USER CODE END RTOS_QUEUES */

  /* Create the thread(s) */
  /* creation of TaskToit */
  TaskToitHandle = osThreadNew(StartTaskToit, NULL, &TaskToit_attributes);

  /* creation of TaskBle */
  TaskBleHandle = osThreadNew(StartTaskBle, NULL, &TaskBle_attributes);

  /* creation of TaskDiag */
  TaskDiagHandle = osThreadNew(StartTaskDiag, NULL, &TaskDiag_attributes);

  /* USER CODE BEGIN RTOS_THREADS */
  /* add threads, ... */
  /* USER CODE END RTOS_THREADS */

  /* USER CODE BEGIN RTOS_EVENTS */
  /* add events, ... */
  /* USER CODE END RTOS_EVENTS */

  /* Start scheduler */
  osKernelStart();

  /* We should never get here as control is now taken by the scheduler */

  /* Infinite loop */
  /* USER CODE BEGIN WHILE */
  while (1)
  {
    /* USER CODE END WHILE */

    /* USER CODE BEGIN 3 */
  }
  /* USER CODE END 3 */
}

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
/* USER CODE BEGIN Header_StartTaskToit */
/**
  * @brief  Function implementing the TaskToit thread.
  * @param  argument: Not used
  * @retval None
  */
/* USER CODE END Header_StartTaskToit */
void StartTaskToit(void *argument)
{
  /* USER CODE BEGIN 5 */
  /* Infinite loop */
  for(;;)
  {
    Vitres_Process();
    osDelay(20);
  }
  /* USER CODE END 5 */
}

/* USER CODE BEGIN Header_StartTaskBle */
/**
* @brief Function implementing the TaskBle thread.
* @param argument: Not used
* @retval None
*/
/* USER CODE END Header_StartTaskBle */
void StartTaskBle(void *argument)
{
  /* USER CODE BEGIN StartTaskBle */
  /* Infinite loop */
  for(;;)
  {
    osDelay(1);
  }
  /* USER CODE END StartTaskBle */
}

/* USER CODE BEGIN Header_StartTaskDiag */
/**
* @brief Function implementing the TaskDiag thread.
* @param argument: Not used
* @retval None
*/
/* USER CODE END Header_StartTaskDiag */
void StartTaskDiag(void *argument)
{
  /* USER CODE BEGIN StartTaskDiag */
  /* Infinite loop */
  for(;;)
  {
    osDelay(1);
  }
  /* USER CODE END StartTaskDiag */
}

/**
  * @brief  Period elapsed callback in non blocking mode
  * @note   This function is called  when TIM4 interrupt took place, inside
  * HAL_TIM_IRQHandler(). It makes a direct call to HAL_IncTick() to increment
  * a global variable "uwTick" used as application time base.
  * @param  htim : TIM handle
  * @retval None
  */
void HAL_TIM_PeriodElapsedCallback(TIM_HandleTypeDef *htim)
{
  if (htim->Instance == TIM4)
  {
    HAL_IncTick();
  }
}

/**
  * @brief  This function is executed in case of error occurrence.
  * @retval None
  */
void Error_Handler(void)
{
  /* USER CODE BEGIN Error_Handler_Debug */
  /* User can add his own implementation to report the HAL error return state */
  __disable_irq();
  while (1)
  {
  }
  /* USER CODE END Error_Handler_Debug */
}
#ifdef USE_FULL_ASSERT
/**
  * @brief  Reports the name of the source file and the source line number
  *         where the assert_param error has occurred.
  * @param  file: pointer to the source file name
  * @param  line: assert_param error line source number
  * @retval None
  */
void assert_failed(uint8_t *file, uint32_t line)
{
  /* USER CODE BEGIN 6 */
  /* User can add his own implementation to report the file name and line number,
     ex: printf("Wrong parameters value: file %s on line %d\r\n", file, line) */
  /* USER CODE END 6 */
}
#endif /* USE_FULL_ASSERT */

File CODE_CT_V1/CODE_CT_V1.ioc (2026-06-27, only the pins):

Mcu.UserName=STM32F103RBTx
PA0-WKUP.GPIO_Label=ADC_TABLETTE_RANGEE_SORTIE
PA0-WKUP.Signal=ADCx_IN0
PA1.GPIO_Label=ADC_TEMP_MOTEUR_POMPE
PA1.Signal=ADCx_IN1
PA10.GPIO_Label=UART_BT_RX
PA10.Signal=USART1_RX
PA11.GPIO_Label=UART_BT_CTS
PA11.Signal=USART1_CTS
PA12.GPIO_Label=UART_BT_RTS
PA12.Signal=USART1_RTS
PA13.Signal=SYS_JTMS-SWDIO
PA14.Signal=SYS_JTCK-SWCLK
PA2.GPIO_Label=ADC_COURANT_1
PA2.Signal=ADCx_IN2
PA3.GPIO_Label=ADC_COURANT_2
PA3.Signal=ADCx_IN3
PA8.GPIO_Label=BT_RESET
PA8.Signal=GPIO_Output
PA9.GPIO_Label=UART_BT_TX
PA9.Signal=USART1_TX
PB0.GPIO_Label=IN_VITRE_1
PB0.Signal=GPIO_Input
PB1.GPIO_Label=IN_VITRE_2
PB1.Signal=GPIO_Input
PB10.GPIO_Label=UART_AD_TX
PB10.Signal=USART3_TX
PB11.GPIO_Label=UART_AD_RX
PB11.Signal=USART3_RX
PB12.GPIO_Label=OUT_BSI_1
PB12.Signal=GPIO_Output
PB13.GPIO_Label=OUT_BSI_0
PB13.Signal=GPIO_Output
PB2.GPIO_Label=IN_VITRE_3
PB2.Signal=GPIO_Input
PB3.GPIO_Label=IN_VITRE_4
PB3.Signal=GPIO_Input
PB4.GPIO_Label=OUT_3B
PB4.Signal=GPIO_Output
PB5.GPIO_Label=OUT_3A
PB5.Signal=GPIO_Output
PB6.GPIO_Label=OUT_2B
PB6.Signal=GPIO_Output
PB7.GPIO_Label=OUT_2A
PB7.Signal=GPIO_Output
PB8.GPIO_Label=OUT_1B
PB8.Signal=GPIO_Output
PB9.GPIO_Label=OUT_1A
PB9.Signal=GPIO_Output
PC0.GPIO_Label=OUT_RELAIS_POMPE
PC0.Signal=GPIO_Output
PC1.GPIO_Label=OUT_RELAI_POMPE_0
PC1.Signal=GPIO_Output
PC10.GPIO_Label=IN_MALLE_VERROUILLEE_G_D
PC10.Signal=GPIO_Input
PC11.GPIO_Label=IN_TOIT_FERME
PC11.Signal=GPIO_Input
PC12.GPIO_Label=IN_MALLE_OUVERTE
PC12.Signal=GPIO_Input
PC13-TAMPER-RTC.GPIO_Label=IN_VITESSE
PC13-TAMPER-RTC.Signal=GPIO_Input
PC14-OSC32_IN.GPIO_Label=IN_MOTEUR_TOURNANT
PC14-OSC32_IN.Signal=GPIO_Input
PC15-OSC32_OUT.GPIO_Label=IN_BTN_TOIT_FERMER
PC15-OSC32_OUT.Signal=GPIO_Input
PC2.GPIO_Label=OUT_RELAI_POMPE_1
PC2.Signal=GPIO_Output
PC3.GPIO_Label=OUT_ALIM_VANNE
PC3.Signal=GPIO_Output
PC4.GPIO_Label=IN_TOIT_OUVERT
PC4.Signal=GPIO_Input
PC5.GPIO_Label=IN_COFFRE_FERME
PC5.Signal=GPIO_Input
PC6.GPIO_Label=IN_TOIT_VERROUILLE_G
PC6.Signal=GPIO_Input
PC7.GPIO_Label=IN_TOIT_VERROUILLE_D
PC7.Signal=GPIO_Input
PC8.GPIO_Label=IN_RIDEAU
PC8.Signal=GPIO_Input
PC9.GPIO_Label=IN_BTN_TOIT_OUVRIR
PC9.Signal=GPIO_Input
PD0-OSC_IN.Signal=RCC_OSC_IN
PD1-OSC_OUT.Signal=RCC_OSC_OUT

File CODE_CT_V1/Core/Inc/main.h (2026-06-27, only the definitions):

#define IN_VITESSE_Pin GPIO_PIN_13
#define IN_VITESSE_GPIO_Port GPIOC
#define IN_MOTEUR_TOURNANT_Pin GPIO_PIN_14
#define IN_MOTEUR_TOURNANT_GPIO_Port GPIOC
#define IN_BTN_TOIT_FERMER_Pin GPIO_PIN_15
#define IN_BTN_TOIT_FERMER_GPIO_Port GPIOC
#define OUT_RELAIS_POMPE_Pin GPIO_PIN_0
#define OUT_RELAIS_POMPE_GPIO_Port GPIOC
#define OUT_RELAI_POMPE_0_Pin GPIO_PIN_1
#define OUT_RELAI_POMPE_0_GPIO_Port GPIOC
#define OUT_RELAI_POMPE_1_Pin GPIO_PIN_2
#define OUT_RELAI_POMPE_1_GPIO_Port GPIOC
#define OUT_ALIM_VANNE_Pin GPIO_PIN_3
#define OUT_ALIM_VANNE_GPIO_Port GPIOC
#define ADC_TABLETTE_RANGEE_SORTIE_Pin GPIO_PIN_0
#define ADC_TABLETTE_RANGEE_SORTIE_GPIO_Port GPIOA
#define ADC_TEMP_MOTEUR_POMPE_Pin GPIO_PIN_1
#define ADC_TEMP_MOTEUR_POMPE_GPIO_Port GPIOA
#define ADC_COURANT_1_Pin GPIO_PIN_2
#define ADC_COURANT_1_GPIO_Port GPIOA
#define ADC_COURANT_2_Pin GPIO_PIN_3
#define ADC_COURANT_2_GPIO_Port GPIOA
#define IN_TOIT_OUVERT_Pin GPIO_PIN_4
#define IN_TOIT_OUVERT_GPIO_Port GPIOC
#define IN_COFFRE_FERME_Pin GPIO_PIN_5
#define IN_COFFRE_FERME_GPIO_Port GPIOC
#define IN_VITRE_1_Pin GPIO_PIN_0
#define IN_VITRE_1_GPIO_Port GPIOB
#define IN_VITRE_2_Pin GPIO_PIN_1
#define IN_VITRE_2_GPIO_Port GPIOB
#define IN_VITRE_3_Pin GPIO_PIN_2
#define IN_VITRE_3_GPIO_Port GPIOB
#define UART_AD_TX_Pin GPIO_PIN_10
#define UART_AD_TX_GPIO_Port GPIOB
#define UART_AD_RX_Pin GPIO_PIN_11
#define UART_AD_RX_GPIO_Port GPIOB
#define OUT_BSI_1_Pin GPIO_PIN_12
#define OUT_BSI_1_GPIO_Port GPIOB
#define OUT_BSI_0_Pin GPIO_PIN_13
#define OUT_BSI_0_GPIO_Port GPIOB
#define IN_TOIT_VERROUILLE_G_Pin GPIO_PIN_6
#define IN_TOIT_VERROUILLE_G_GPIO_Port GPIOC
#define IN_TOIT_VERROUILLE_D_Pin GPIO_PIN_7
#define IN_TOIT_VERROUILLE_D_GPIO_Port GPIOC
#define IN_RIDEAU_Pin GPIO_PIN_8
#define IN_RIDEAU_GPIO_Port GPIOC
#define IN_BTN_TOIT_OUVRIR_Pin GPIO_PIN_9
#define IN_BTN_TOIT_OUVRIR_GPIO_Port GPIOC
#define BT_RESET_Pin GPIO_PIN_8
#define BT_RESET_GPIO_Port GPIOA
#define UART_BT_TX_Pin GPIO_PIN_9
#define UART_BT_TX_GPIO_Port GPIOA
#define UART_BT_RX_Pin GPIO_PIN_10
#define UART_BT_RX_GPIO_Port GPIOA
#define UART_BT_CTS_Pin GPIO_PIN_11
#define UART_BT_CTS_GPIO_Port GPIOA
#define UART_BT_RTS_Pin GPIO_PIN_12
#define UART_BT_RTS_GPIO_Port GPIOA
#define IN_MALLE_VERROUILLEE_G_D_Pin GPIO_PIN_10
#define IN_MALLE_VERROUILLEE_G_D_GPIO_Port GPIOC
#define IN_TOIT_FERME_Pin GPIO_PIN_11
#define IN_TOIT_FERME_GPIO_Port GPIOC
#define IN_MALLE_OUVERTE_Pin GPIO_PIN_12
#define IN_MALLE_OUVERTE_GPIO_Port GPIOC
#define IN_VITRE_4_Pin GPIO_PIN_3
#define IN_VITRE_4_GPIO_Port GPIOB
#define OUT_3B_Pin GPIO_PIN_4
#define OUT_3B_GPIO_Port GPIOB
#define OUT_3A_Pin GPIO_PIN_5
#define OUT_3A_GPIO_Port GPIOB
#define OUT_2B_Pin GPIO_PIN_6
#define OUT_2B_GPIO_Port GPIOB
#define OUT_2A_Pin GPIO_PIN_7
#define OUT_2A_GPIO_Port GPIOB
#define OUT_1B_Pin GPIO_PIN_8
#define OUT_1B_GPIO_Port GPIOB
#define OUT_1A_Pin GPIO_PIN_9
#define OUT_1A_GPIO_Port GPIOB

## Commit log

2026-06-27 Premier commit : ajout de toute la structure
    [185534-3--3DModel-STEP-1.STEP, ABM3B-8.000MHZ-10-1UT--3DModel-STEP-400430.STEP, LM2936MP-3.3.step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]
2026-06-27 Correction : Intégration complète du code et de l'historique CAO
    [CODE_CT_V1.ioc, main.c, main.h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]
2026-06-27 Sauvegarde de la configuration VS Code et Workspace

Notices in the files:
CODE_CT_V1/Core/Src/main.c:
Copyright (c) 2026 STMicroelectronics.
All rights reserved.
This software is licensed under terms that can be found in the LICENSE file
